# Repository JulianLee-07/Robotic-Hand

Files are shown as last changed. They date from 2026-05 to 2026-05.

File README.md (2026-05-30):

# Computer Vision Controlled Robotic Hand

This project is a 3D-printed tendon-driven robotic hand controlled using real-time computer vision. The project combines SolidWorks CAD design, 3D printing, servo actuation, Arduino control, and Python-based hand tracking

## Demo

**Video:** [Watch the demo video](media/demo.mp4)

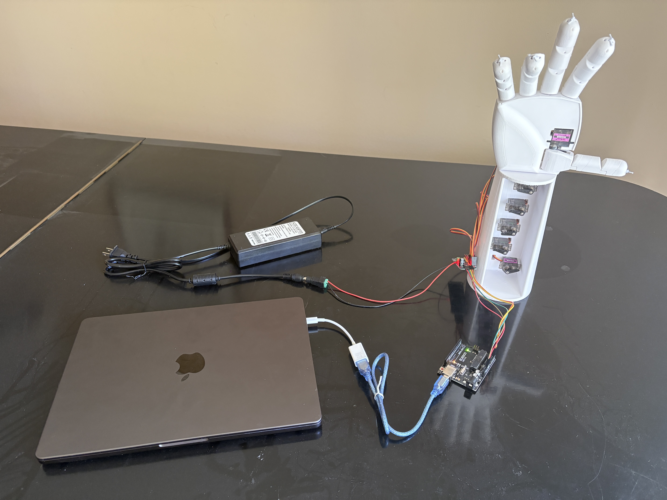
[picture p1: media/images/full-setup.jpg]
Watch the demo video


Click the image above to open the demo video.

## Overview

The system tracks a human hand using a webcam, estimates finger openness from hand landmarks, and sends servo commands to a robotic hand

```text
Webcam → Python/OpenCV/MediaPipe → Arduino → PCA9685 → Servo motors → Tendons → Robotic hand
```

## Features

- Real-time hand tracking using OpenCV and MediaPipe
- Tendon-driven finger actuation using fishing line
- Elastic extension system for reopening fingers
- Arduino serial control
- PCA9685 16-channel servo driver
- Custom SolidWorks CAD design
- Servo calibration script for finding safe open and closed pulse values
- 3D-printable STL files included

## Project Images

### CAD Render

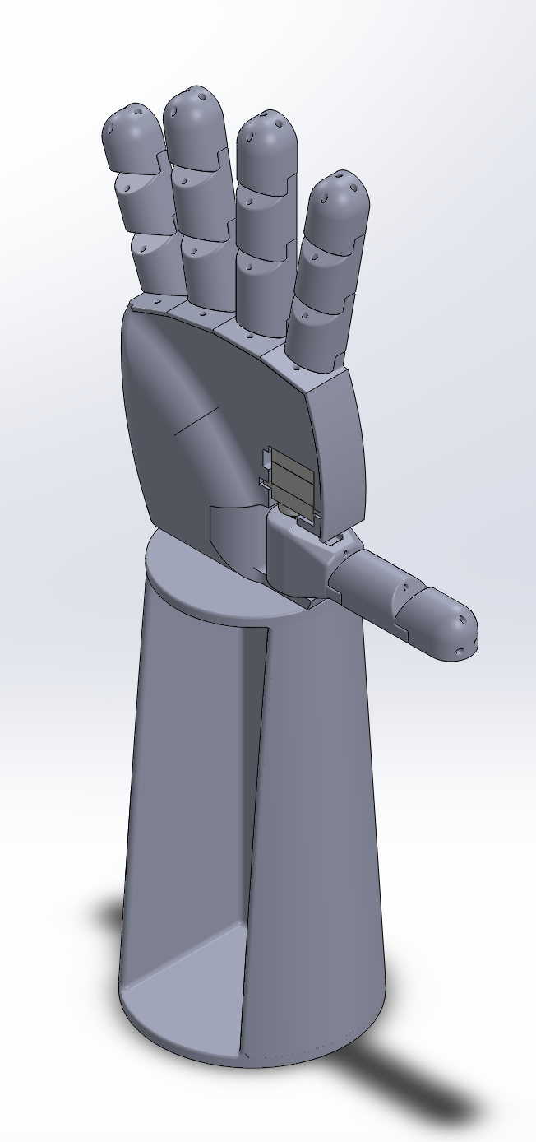
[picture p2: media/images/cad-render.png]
CAD render


### Electrical Setup

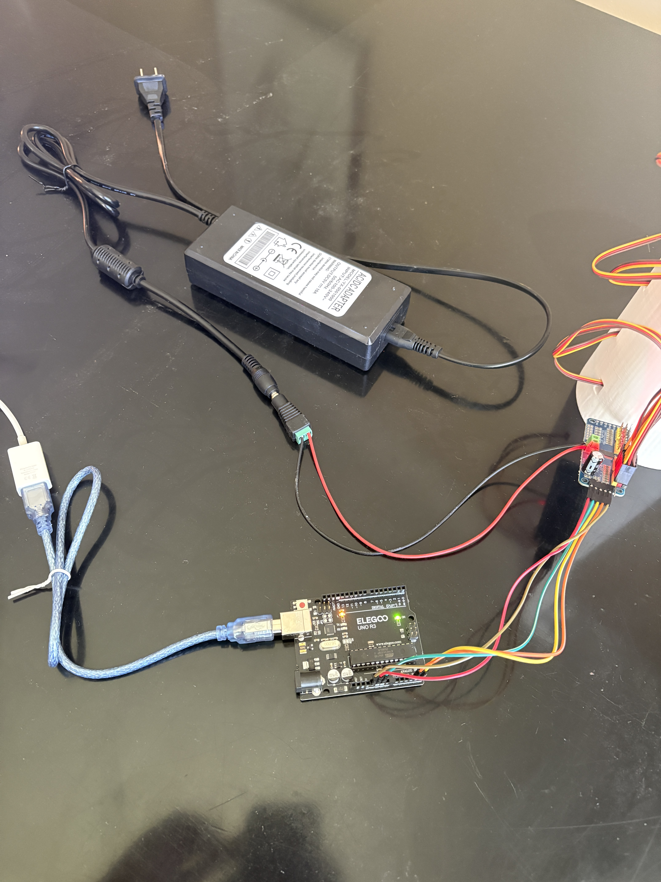
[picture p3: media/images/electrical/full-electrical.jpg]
Full electrical setup


## Hardware

Main hardware used:

- Arduino Uno
- PCA9685 16-channel servo driver
- MG90S micro servo motors
- 5V 10A external power supply
- Fishing line for tendons
- Elastic cord / rubber bands for finger return
- 3D-printed hand parts
- Webcam or laptop camera

More details are in [`docs/BOM.md`](docs/BOM.md).

## Software

The main software is located in [`software/python`](software/python).

Important files:

| File | Purpose |
| --- | --- |
| `vision_servo_control.py` | Main computer vision control script  |
| `servo_calibration.py` | Interactive servo calibration script |
| `requirements.txt` | Python dependencies |

The Arduino sketch is located in:

```text
software/arduino/robotic_hand_serial_controller/
```

## CAD Files

The CAD files are located in [`cad`](cad).

| Folder/File | Purpose |
| --- | --- |
| `cad/Full Robotic Hand.SLDASM` | Main SolidWorks assembly |
| `cad/Parts/` | Editable SolidWorks part files |
| `cad/Printing Files/` | Exported STL files for 3D printing |
| `cad/diagrams/hand-segment-map.png` | Finger segment reference map |

## Finger Segment Map

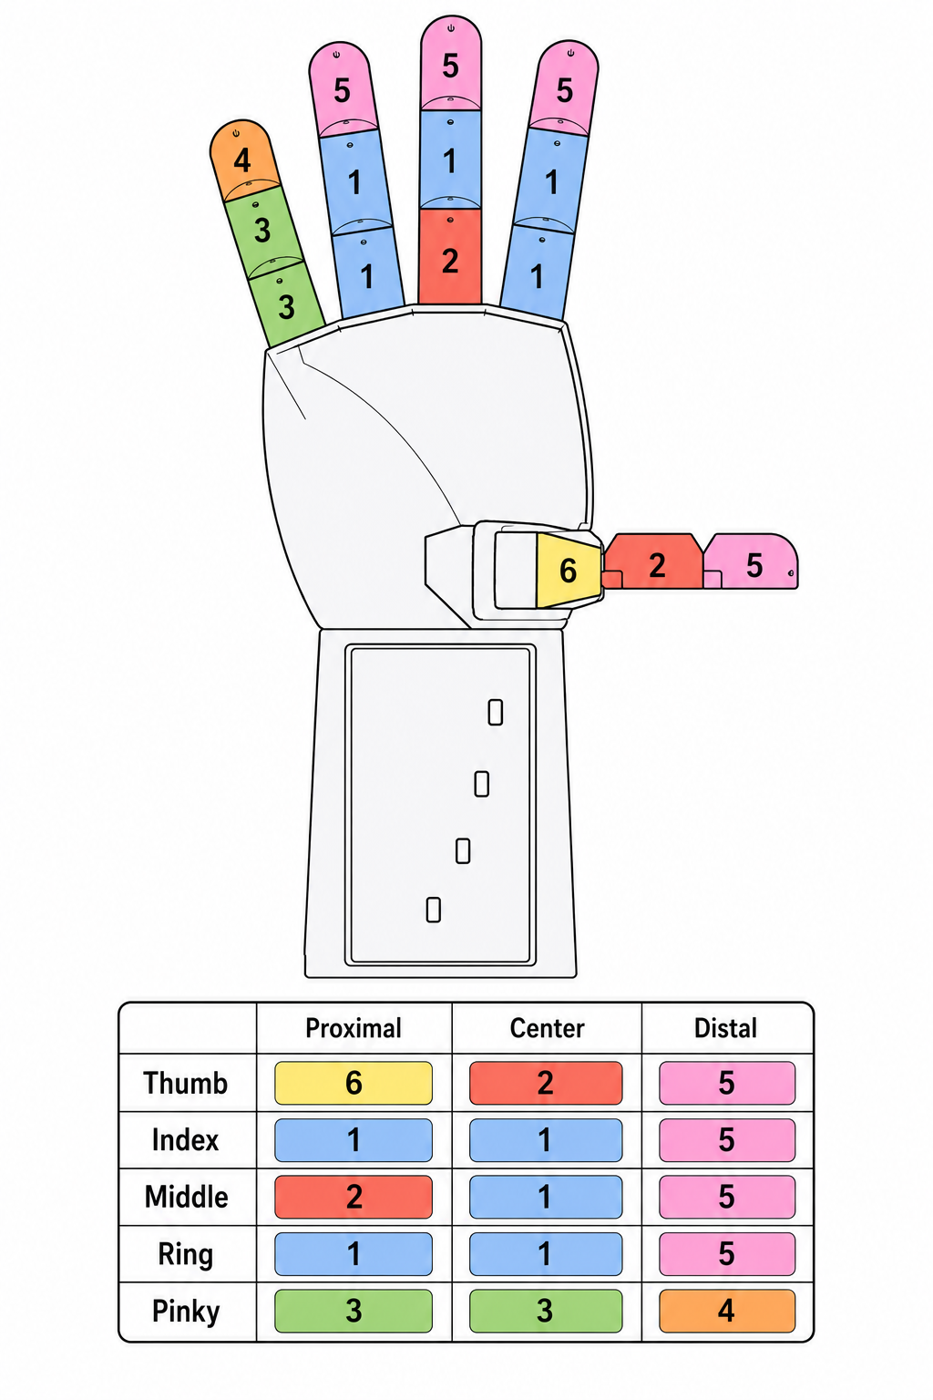
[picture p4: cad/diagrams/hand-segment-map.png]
Hand segment map


## Wiring

Wiring details are documented in [`docs/wiring.md`](docs/wiring.md).

Servo channel map:

| PCA9685 Channel | Servo |
| ---: | --- |
| 0 | Thumb rotation |
| 1 | Thumb curl |
| 2 | Index |
| 3 | Middle |
| 4 | Ring |
| 5 | Pinky |

## Running the Project

### 1. Install Python dependencies

From the project root:

```bash
cd software/python
python3 -m venv .venv
source .venv/bin/activate
pip install -r requirements.txt
```

### 2. Upload the Arduino sketch

Open this sketch in Arduino IDE:

```text
software/arduino/robotic_hand_serial_controller/robotic_hand_serial_controller.ino
```

Upload it to the Arduino Uno.

### 3. Check the Arduino port

On macOS, run:

```bash
ls /dev/cu.*
```

Update the `PORT` value in the Python scripts if needed.

Example:

```python
PORT = "/dev/cu.usbmodem3101"
```

### 4. Calibrate servos

Run:

```bash
python3 servo_calibration.py
```

Use this script to manually find the safe open and closed pulse values for each servo.

### 5. Run vision control

Run:

```bash
python3 vision_servo_control.py
```

Press `q` to quit.

## Calibration Notes

Each servo has custom open and closed pulse values because the mechanical range, servo orientation, tendon tension, and tendon routing vary between fingers.

The calibration script saves local calibration values to:

```text
servo_calibration.json
```

This file is ignored by Git because it is specific to the local mechanical setup.

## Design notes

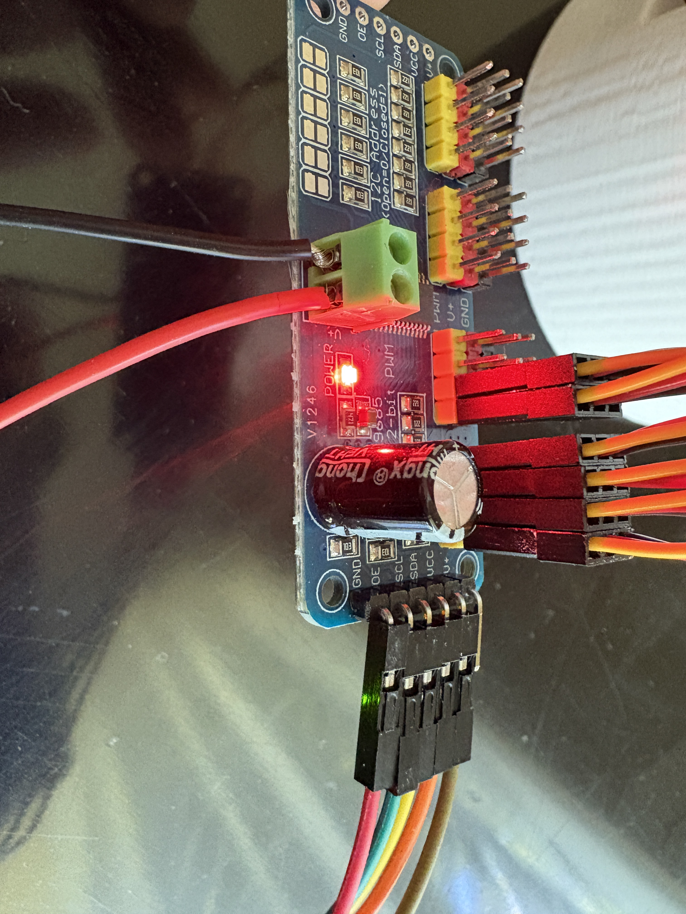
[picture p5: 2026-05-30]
media/images/electrical/pca9685-servo-controller.jpg

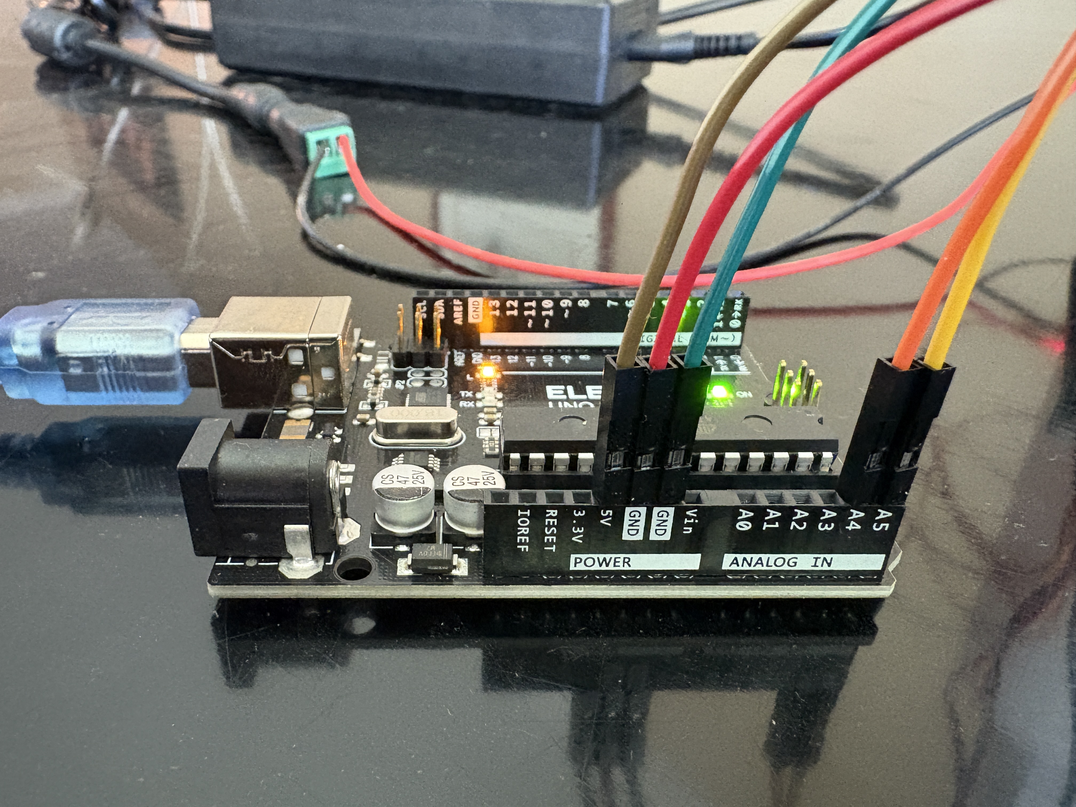
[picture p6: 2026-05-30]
media/images/electrical/arduino.jpg

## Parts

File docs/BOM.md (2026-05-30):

# Bill of Materials

| Item |  Quantity | Notes |
| --- | ---: | --- |
| Arduino Uno | 1 | Main microcontroller |
| PCA9685 servo driver | 1 | Controls servo motors using PWM |
| MG90S micro servo motors | 6 | Drive finger and thumb movement |
| 5V 10A DC power supply | 1 | External servo power |
| Female DC barrel connector | 1 | Connects power supply to PCA9685 |
| Jumper wires | As needed | Arduino to PCA9685 wiring |
| 20 AWG red/black wire | As needed | Power supply to PCA9685 wiring |
| Fishing line | As needed | Tendons for finger flexion |
| Elastic cord | As needed | Return mechanism for finger extension |
| 3D printer filament | As needed | Printed hand, palm, wrist, and finger parts |
| Webcam / laptop camera | 1 | Computer vision input |
| Laptop | 1 | Runs Python control script |

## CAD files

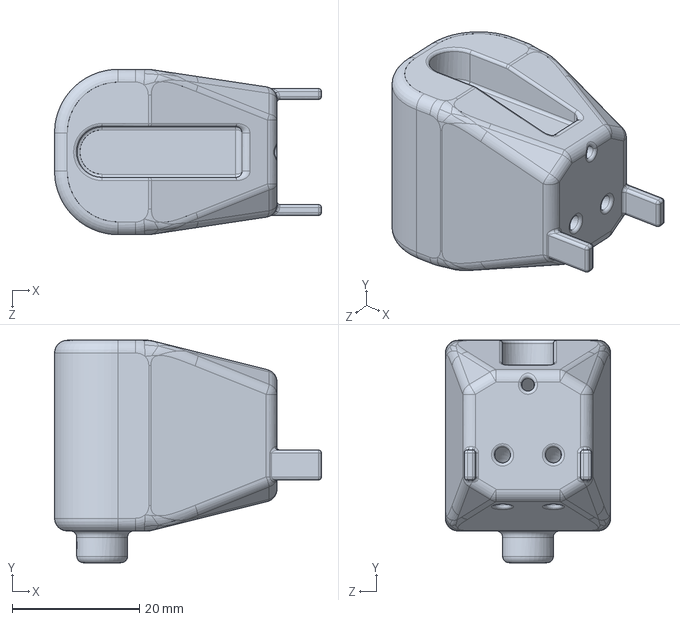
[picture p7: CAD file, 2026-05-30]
cad/Parts/finger-segment 6.SLDPRT
42.0 x 35.0 x 26.0 mm

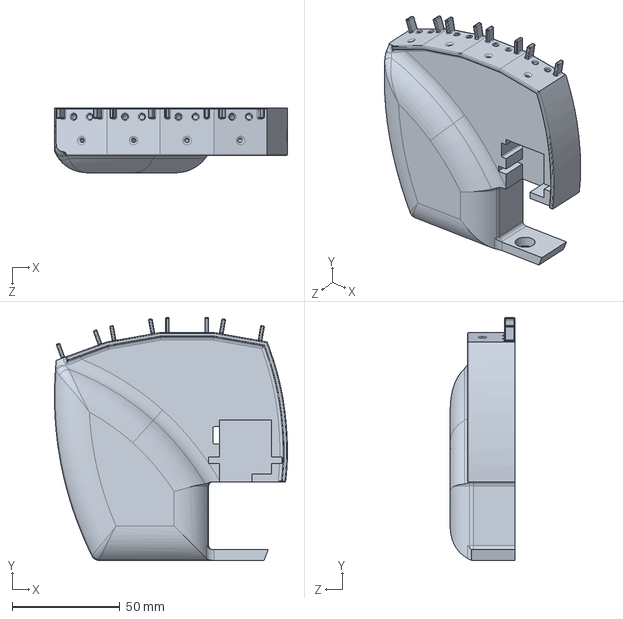
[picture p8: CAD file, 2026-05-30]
cad/Parts/Palm.SLDPRT
107.9 x 112.6 x 30.0 mm

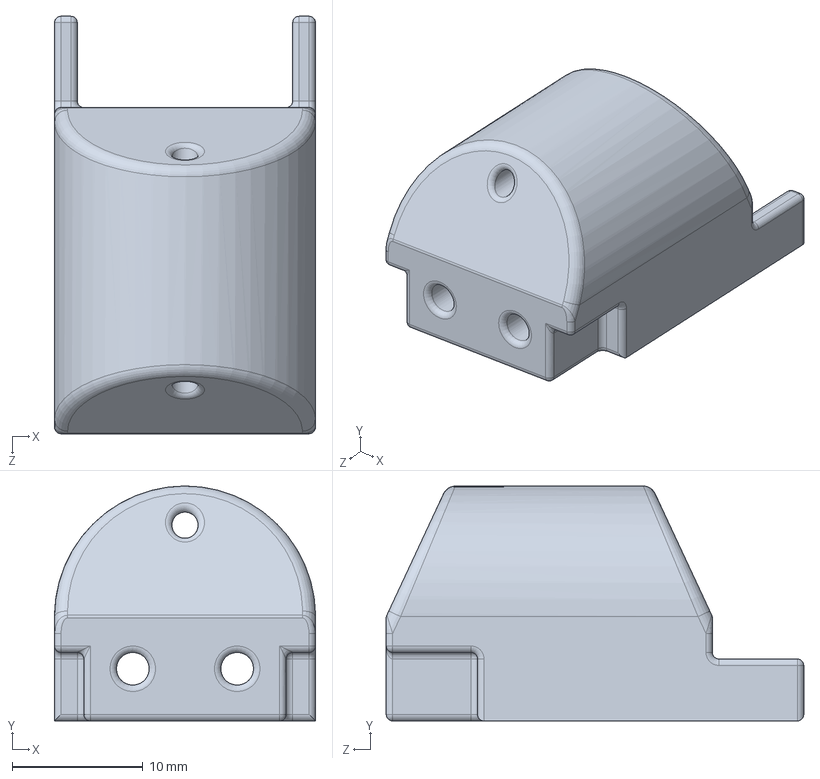
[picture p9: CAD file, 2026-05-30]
cad/Parts/finger-segment 3.SLDPRT
20.0 x 18.0 x 32.0 mm

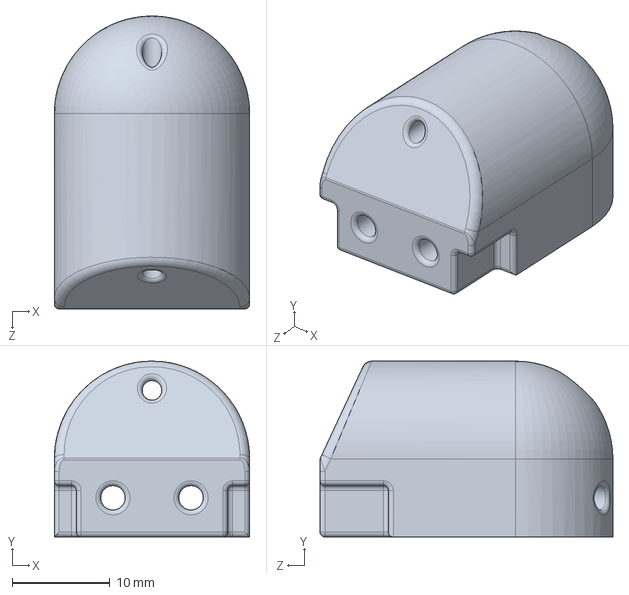
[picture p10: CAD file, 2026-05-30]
cad/Parts/finger-segment 5.SLDPRT
20.0 x 18.0 x 30.0 mm

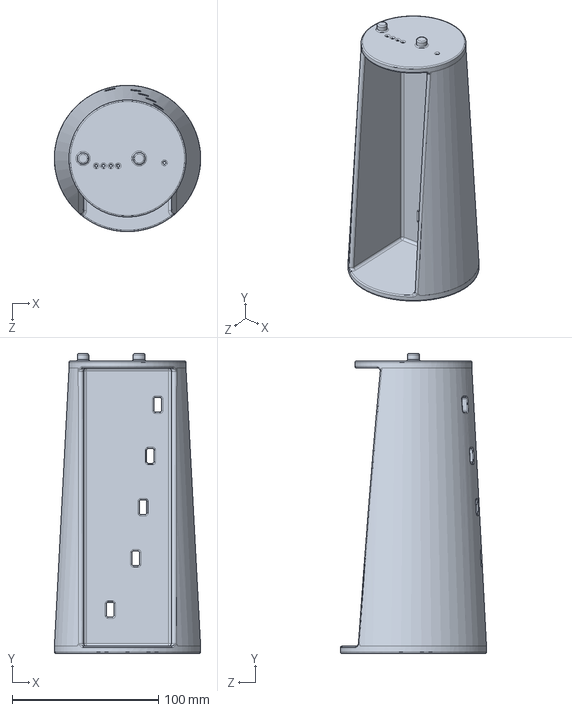
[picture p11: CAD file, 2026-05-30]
cad/Parts/Wrist.SLDPRT
100.0 x 205.0 x 100.0 mm

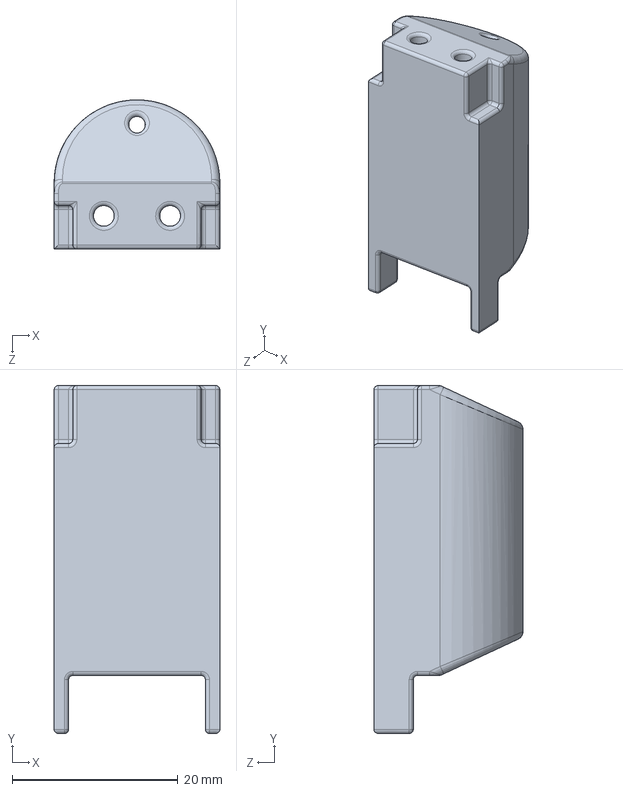
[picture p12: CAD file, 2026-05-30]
cad/Parts/finger-segment 2.SLDPRT
20.0 x 42.0 x 18.0 mm

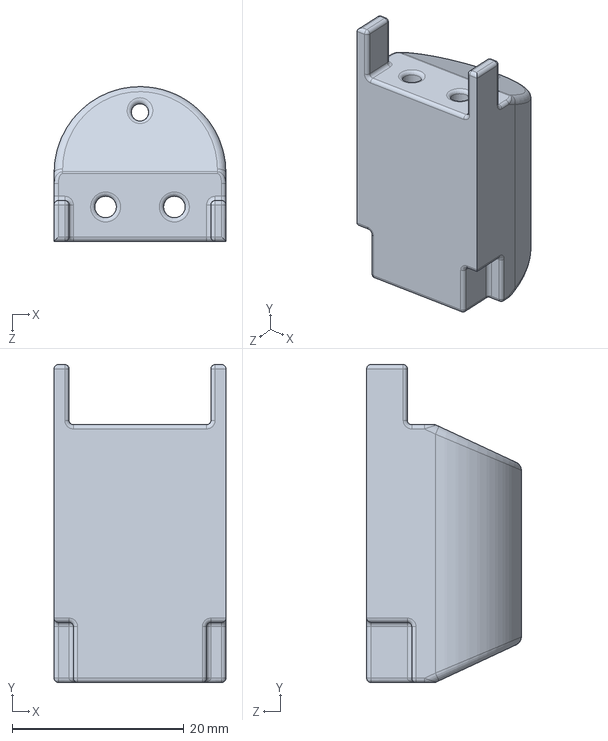
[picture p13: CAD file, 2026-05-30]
cad/Parts/finger-segment 1.SLDPRT
20.0 x 37.0 x 18.0 mm

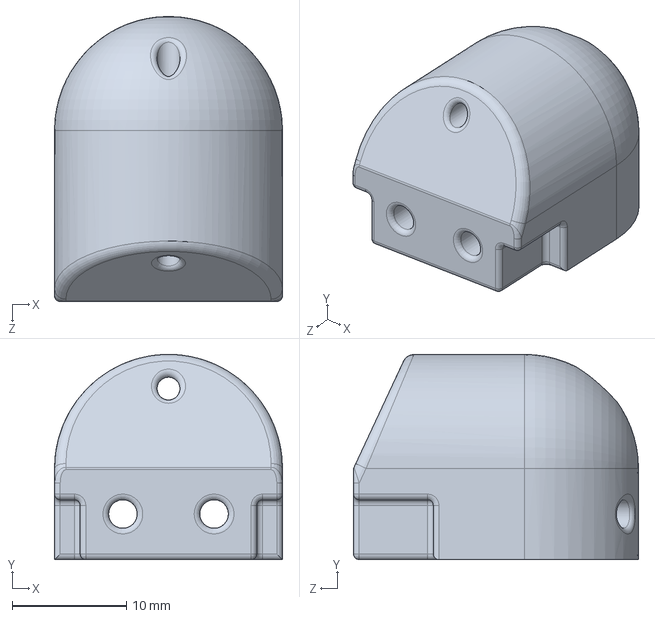
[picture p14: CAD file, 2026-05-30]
cad/Parts/finger-segment 4.SLDPRT
20.0 x 18.0 x 25.0 mm

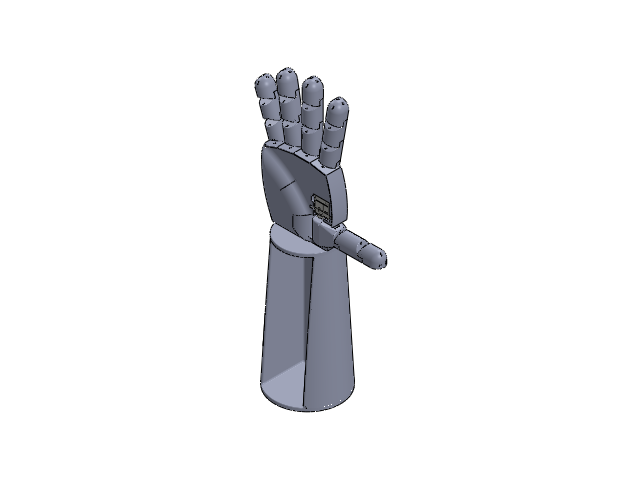
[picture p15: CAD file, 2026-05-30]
cad/Full Robotic Hand.SLDASM
Palm
Micro Motor.step
Middel Part.step
Buttom Part.step
Shaft B.step
Gear C.step
Gear B.step
Gear A.step
Main Shaft with Gear.step
Upper Part.step
Main Screw.step x 2
(6) Thumb Rotating Inner Piece
Wrist
(2) Middle, thumb proximal segment x 2
(5) Ring, Middle, Index, Thumb distal segment x 4
(1) Index, Middle, Ring center + Index, ring proximal segment x 5
(3) Pinky center + Pinky Proximal segment x 2
(4) Pinky distal segment

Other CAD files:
cad/Printing Files/Palm.STL
cad/Printing Files/Wrist.STL
cad/Printing Files/finger-segment 1.STL
cad/Printing Files/finger-segment 2.STL
cad/Printing Files/finger-segment 3.STL
cad/Printing Files/finger-segment 4.STL
cad/Printing Files/finger-segment 5.STL
cad/Printing Files/finger-segment 6.STL

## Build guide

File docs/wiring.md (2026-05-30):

# Wiring

## Arduino to PCA9685

| Arduino Uno | PCA9685 | Purpose |
| --- | --- | --- |
| 5V | VCC | Logic power for PCA9685 |
| GND | GND | Shared ground |
| A4 | SDA | I2C data |
| A5 | SCL | I2C clock |
| GND | OE | Keeps PCA9685 outputs enabled |

## External Servo Power

| Power Supply | PCA9685 |
| --- | --- |
| +5V | V+ screw terminal  |
| GND / - | GND screw terminal |

## Servo Connections

Each servo plugs into one PCA9685 channel.

| Servo Wire | PCA9685 Row |
| --- | --- |
| Orange / Yellow | PWM |
| Red | V+ |
| Brown / Black | GND |

## Servo Channel Map

| PCA9685 Channel | Servo |
| ---: | --- |
| 0 | Thumb rotation |
| 1 | Thumb curl |
| 2 | Index |
| 3 | Middle |
| 4 | Ring |
| 5 | Pinky |

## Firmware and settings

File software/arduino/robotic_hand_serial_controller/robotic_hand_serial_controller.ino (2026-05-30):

#include <Wire.h>
#include <Adafruit_PWMServoDriver.h>

Adafruit_PWMServoDriver pwm = Adafruit_PWMServoDriver(0x40);

const int NUM_SERVOS = 6;

// Safe initial pulse limits.
// Later, when the hand is assembled, we will tune these per finger.
const int MIN_PULSE = 500;
const int MID_PULSE = 1500;
const int MAX_PULSE = 2500;

void moveServo(int channel, int pulse) {
  if (channel < 0 || channel >= NUM_SERVOS) {
    Serial.println("ERROR: invalid channel");
    return;
  }

  pulse = constrain(pulse, MIN_PULSE, MAX_PULSE);

  pwm.writeMicroseconds(channel, pulse);

  Serial.print("OK: channel ");
  Serial.print(channel);
  Serial.print(" -> ");
  Serial.println(pulse);
}

void centerAll() {
  for (int ch = 0; ch < NUM_SERVOS; ch++) {
    moveServo(ch, MID_PULSE);
    delay(150);
  }
}

void setup() {
  Serial.begin(115200);
  delay(1000);

  Serial.println("Starting robotic hand serial servo controller...");

  pwm.begin();
  pwm.setPWMFreq(50);
  delay(10);

  Serial.println("Ready.");
  Serial.println("Send commands like:");
  Serial.println("0 1500");
  Serial.println("1 1700");
  Serial.println("all 1500");
}

void loop() {
  if (Serial.available() > 0) {
    String line = Serial.readStringUntil('\n');
    line.trim();

    if (line.length() == 0) {
      return;
    }

    if (line.startsWith("all")) {
      int spaceIndex = line.indexOf(' ');
      if (spaceIndex == -1) {
        Serial.println("ERROR: use all 1500");
        return;
      }

      int pulse = line.substring(spaceIndex + 1).toInt();

      for (int ch = 0; ch < NUM_SERVOS; ch++) {
        moveServo(ch, pulse);
        delay(100);
      }

      return;
    }

    int spaceIndex = line.indexOf(' ');
    if (spaceIndex == -1) {
      Serial.println("ERROR: use channel pulse, example: 0 1500");
      return;
    }

    int channel = line.substring(0, spaceIndex).toInt();
    int pulse = line.substring(spaceIndex + 1).toInt();

    moveServo(channel, pulse);
  }
}

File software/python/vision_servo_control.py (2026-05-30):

"""
This file contains the computer vision controller for the robotic hand

It tracks a human hand with MediaPipe, estimates finger openness from joint
angles, maps those scores to calibrated servo pulse values, and sends
commands to an Arduino over serial
"""

import math
import time
from typing import Optional

import cv2
import mediapipe as mp
import serial

# Connection settings
# Run ls /dev/cu.* in your terminal to find the correct port
# Ensure BAUD_RATE matches the baud rate in your Arduino code
PORT = "/dev/cu.usbmodem3101"
BAUD_RATE = 115200
CAMERA_INDEX = 1

# Servo config
# Ensure channels match your wiring in PCA9685 and Arduino code
# Use servo_calibration.py to find the correct open/closed pulse values for your hand
SERVO_CONFIG = {
    "thumb_rotation": {
        "channel": 0,
        "open_pulse": 500,
        "closed_pulse": 1050,
    },
    "thumb_curl": {
        "channel": 1,
        "open_pulse": 2000,
        "closed_pulse": 650,
    },
    "index": {
        "channel": 2,
        "open_pulse": 770,
        "closed_pulse": 1970,
    },
    "middle": {
        "channel": 3,
        "open_pulse": 1090,
        "closed_pulse": 2460,
    },
    "ring": {
        "channel": 4,
        "open_pulse": 770,
        "closed_pulse": 1970,
    },
    "pinky": {
        "channel": 5,
        "open_pulse": 900,
        "closed_pulse": 2150,
    },
}

# Vision settings
FINGER_CLOSED_ANGLE = 65.0
FINGER_OPEN_ANGLE = 175.0

THUMB_CLOSED_ANGLE = 80.0
THUMB_OPEN_ANGLE = 175.0

SMOOTHING = 0.45
MAX_PULSE_CHANGE_PER_UPDATE = 80
SEND_INTERVAL_SECONDS = 0.03

THUMB_OBSERVED_CLOSED_SCORE = 0.4
THUMB_OBSERVED_OPEN_SCORE = 1.00

# Landmarks
FINGER_MCP = {
    "index": 5,
    "middle": 9,
    "ring": 13,
    "pinky": 17,
}

FINGER_PIP = {
    "index": 6,
    "middle": 10,
    "ring": 14,
    "pinky": 18,
}

FINGER_TIP = {
    "index": 8,
    "middle": 12,
    "ring": 16,
    "pinky": 20,
}

THUMB_CMC = 1
THUMB_MCP = 2
THUMB_IP = 3
THUMB_TIP = 4


def clamp(value: float, low: float, high: float) -> float:
    return max(low, min(high, value))


def map_range(
    value: float,
    in_min: float,
    in_max: float,
    out_min: float,
    out_max: float,
) -> float:
    value = clamp(value, in_min, in_max)
    ratio = (value - in_min) / (in_max - in_min)
    return out_min + ratio * (out_max - out_min)


def landmark_to_tuple(landmark) -> tuple[float, float, float]:
    return landmark.x, landmark.y, landmark.z


def vector_from_to(a, b) -> tuple[float, float, float]:
    return b[0] - a[0], b[1] - a[1], b[2] - a[2]


def vector_magnitude(v) -> float:
    return math.sqrt(v[0] ** 2 + v[1] ** 2 + v[2] ** 2)


def angle_between_vectors(v1, v2) -> float:
    mag1 = vector_magnitude(v1)
    mag2 = vector_magnitude(v2)

    if mag1 == 0 or mag2 == 0:
        return 0.0

    dot = v1[0] * v2[0] + v1[1] * v2[1] + v1[2] * v2[2]
    cosine = clamp(dot / (mag1 * mag2), -1.0, 1.0)

    return math.degrees(math.acos(cosine))


def joint_angle(a, b, c) -> float:
    """
    Returns angle ABC in degrees.
    b is the middle joint.
    """
    ba = vector_from_to(b, a)
    bc = vector_from_to(b, c)
    return angle_between_vectors(ba, bc)


def score_to_pulse(servo_name: str, open_score: float) -> int:
    """
    open_score:
      1.0 = fully open
      0.0 = fully closed
    """
    config = SERVO_CONFIG[servo_name]

    open_pulse = config["open_pulse"]
    closed_pulse = config["closed_pulse"]

    pulse = closed_pulse + (open_pulse - closed_pulse) * open_score
    return int(round(pulse))


def limit_pulse_change(previous: Optional[int], desired: int) -> int:
    if previous is None:
        return desired

    difference = desired - previous

    if abs(difference) <= MAX_PULSE_CHANGE_PER_UPDATE:
        return desired

    if difference > 0:
        return previous + MAX_PULSE_CHANGE_PER_UPDATE

    return previous - MAX_PULSE_CHANGE_PER_UPDATE


def send_servo_command(arduino, channel: int, pulse: int) -> None:
    command = f"{channel} {pulse}\n"
    arduino.write(command.encode("utf-8"))


def get_finger_open_scores(hand_landmarks) -> dict[str, float]:
    landmarks = hand_landmarks.landmark
    scores = {}

    for finger in ["index", "middle", "ring", "pinky"]:
        mcp = landmark_to_tuple(landmarks[FINGER_MCP[finger]])
        pip = landmark_to_tuple(landmarks[FINGER_PIP[finger]])
        tip = landmark_to_tuple(landmarks[FINGER_TIP[finger]])

        angle = joint_angle(mcp, pip, tip)

        # Closed finger = lower angle
        # Open finger = higher angle
        open_score = map_range(
            angle,
            FINGER_CLOSED_ANGLE,
            FINGER_OPEN_ANGLE,
            0.0,
            1.0,
        )

        scores[finger] = open_score

    return scores


def get_thumb_open_score(hand_landmarks) -> float:
    landmarks = hand_landmarks.landmark

    thumb_cmc = landmark_to_tuple(landmarks[THUMB_CMC])
    thumb_mcp = landmark_to_tuple(landmarks[THUMB_MCP])
    thumb_ip = landmark_to_tuple(landmarks[THUMB_IP])
    thumb_tip = landmark_to_tuple(landmarks[THUMB_TIP])

    thumb_mcp_angle = joint_angle(thumb_cmc, thumb_mcp, thumb_ip)
    thumb_ip_angle = joint_angle(thumb_mcp, thumb_ip, thumb_tip)

    average_thumb_angle = (thumb_mcp_angle + thumb_ip_angle) / 2.0

    thumb_open_score = map_range(
        average_thumb_angle,
        THUMB_CLOSED_ANGLE,
        THUMB_OPEN_ANGLE,
        0.0,
        1.0,
    )

    return thumb_open_score


def draw_text(frame, text: str, y: int) -> None:
    cv2.putText(
        frame,
        text,
        (20, y),
        cv2.FONT_HERSHEY_SIMPLEX,
        0.75,
        (255, 255, 255),
        2,
    )


def draw_scores(frame, scores: dict[str, float]) -> None:
    y = 40

    draw_text(frame, "Open score: 0.00 = closed, 1.00 = open", y)
    y += 35

    for name in ["thumb", "index", "middle", "ring", "pinky"]:
        score = scores.get(name, 0.0)
        text = f"{name}: {score:.2f}"
        draw_text(frame, text, y)
        y += 35


def open_all_servos(arduino) -> None:
    for config in SERVO_CONFIG.values():
        send_servo_command(arduino, config["channel"], config["open_pulse"])


def calibrate_thumb_score(raw_thumb_score: float) -> float:
    """
    Remaps the thumb score from the camera's actual observed range
    into the full 0.00–1.00 servo control range.

    Example:
      raw score 0.30 -> calibrated score 0.00
      raw score 1.00 -> calibrated score 1.00
    """
    return map_range(
        raw_thumb_score,
        THUMB_OBSERVED_CLOSED_SCORE,
        THUMB_OBSERVED_OPEN_SCORE,
        0.0,
        1.0,
    )
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
